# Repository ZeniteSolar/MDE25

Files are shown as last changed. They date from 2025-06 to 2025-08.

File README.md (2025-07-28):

<!-- PROJECT LOGO -->
<br />
<div align="center">
  <a href="https://github.com/ZeniteSolar/MDE25">
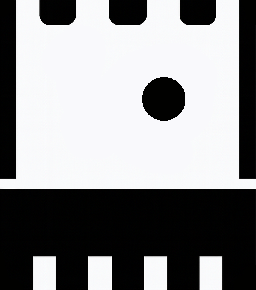
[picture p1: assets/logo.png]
Project Logo
    
  </a>

  <h3 align="center">Módulo de Direção Elétrica 2025 (MDE25)</h3>
</div>

# Visão Geral do Sistema

O sistema de direção elétrica do barco solar é composto por duas placas interligadas, uma de controle e outra de potência. O propósito do sistema é ser capaz de controlar o leme do barco conforme comandos recebidos pela rede CAN do barco enviados pelo Módulo Interface de Controle (MIC).

O barco contém atualmente a revisão [MDE22](https://github.com/ZeniteSolar/MDE22). Como pode ser visto, atualmente o barco contém uma bateria auxiliar de 12V dedicada para alimentar o sistema de direção elétrica, algo que não é tão proveitoso, sendo que o barco possui um banco de baterias principal que é mais que capacitado para alimentar o sistema de direção elétrica. Assim sendo, a bateria auxiliar implica em peso e eletrônica adicional, sendo que requer um Módulo de Carregamento de Bateria Auxiliar.

Tendo em vista a fundamentação acima, a revisão 2025 (MDE25) tem por objetivo:

* Remover a bateria auxiliar de 12V
* Utilizar o banco de baterias principal para alimentar o sistema de direção elétrica
* Melhorar aspectos gerais do sistema, velocidade de resposta, confiabilidade, etc.

Assim sendo, os requisitos abaixo foram definidos, vale notar que vários dos valores já são conhecidos de revisões anteriores, por isso não serão abordados aqui, mas podem ser encontrados no GitHub da [Zenite Solar](https://github.com/ZeniteSolar).

## Requisitos

* Tensão de entrada: 10-60V
* Tensão de saída: 10-60V
* Corrente média nominal: 20-30A
* Corrente média máxima: 42A
* Corrente de pico máxima: 80A
* Full Bridge (Reversão Completa)

## Estrutura do Projeto

Para o desenvolvimento do sistema, tendo em vista que a fabricação das placas foi realizada localmente, ou seja, não se atinge qualidade de empresas especializadas, foi decidido que o sistema seria desenvolvido em duas placas, uma de controle e outra de potência. Permitindo tolerância a erros de fabricação maiores e facilitando a fabricação e manutenção em geral.

---

### 1. Placa de Controle

A placa de controle é responsável por realizar a parte lógica do sistema, bem como gerar as tensões baixas, $V_{DDs}$ em geral e $V_{drive}$. Assim sendo, é constituída majoritariamente por um microcontrolador, um transceptor CAN, e um conjunto de conversores Step-Down / LDOs responsáveis por gerar as tensões necessárias para o sistema.

#### Componentes Principais

* **Microcontrolador:** STM32L431
* **Comunicação:** Rede CAN a 500 kbit/s baseado no transceptor MCP2561.
* **Interfaces:**
  * Conector CAN (também fornece 18 V para alimentação)
  * UART / ST-LINK para programação e depuração
  * Conector para sensor de posição do leme (potenciômetro)
  * Conectores para encoder e fim de curso (redundância)

---

### 2. Placa de Potência

A placa de potência é um sistema extremamente simples, sendo suas únicas funções controlar o motor utilizando uma Ponte H conforme sinais de PWM recebidos da placa de controle, prover sinais de medição, ou seja (Tensão de entrada, Tensão de saída e Corrente de entrada), sendo esses já tratados para serem convertidos pelo ADC do microcontrolador da placa de controle.

## Componentes Principais

* **Topologia:** Ponte H (full-bridge) com dois drivers UCC27211DDAR e quatro MOSFETs BSC093N15NS5.
* **Sensoriamento:**
  * Corrente: shunt de 1 mΩ + amplificador de instrumentação (INA283)
* Tensão: divisor resistivo com filtro passa-baixa de 40 Hz, objetivo de reduzir ruído de chaveamento/ringing.
* **Conectores:**
  * Alimentação principal via KRE (baterias chumbo-ácido 30-42 V ou lítio até 60 V)
  * Saída para motor modelo CIM (modelo FR801‑001)
* **Dissipação térmica:**
  * 5 vias de cobre (Ø 0,7 mm) por MOSFET
  * Thermal pad de 1 mm de espessura e 1 cm² por MOSFET
  * Dissipador montado entre as placas

---

# Fluxo de Sinal e Potência

1. **Entrada de Comando:**
   A placa MIC mede a posição do volante e transmite via CAN o setpoint da posição do leme através da mensagem `CAN_MSG_MIC19_MDE_ID`.

2. **Leitura e Controle:**
   O STM32L431 recebe o comando via CAN, valida o ID e seta o setpoint no controlador PID (utilizando apenas ganho proporcional devido a testes anteriores revelarem conflito entre piloto e ganho integral), que por consequência ajusta o PWM dos drivers conforme o erro entre o setpoint e a posição do leme.

3. **Ponte H:**
   Os drivers UCC27211 acionam os MOSFETs BSC093N15NS5 conforme o PWM gerado. Sendo que pode ser controlada tanto a direção quanto a velocidade do motor através da direção da corrente estabelecida pelo chaveamento e o duty cycle do PWM.

4. **Motor e Feedback:**
   O motor movimenta o leme, cuja posição é retroalimentada via um potenciômetro de 10 kΩ acoplado ao eixo e lido pelo ADC do STM32L431, que por sua vez atualiza a posição atual no controlador PID.

5. **Proteções e Limites:**
   * Monitoramento de corrente via shunt
   * Faixa de tensão de entrada: 10 V a 60 V
   * Faixa de tensão de saída: 0 V a 12 V (Motor projetado para 12 V)
   * Corrente média operacional: 20–30 A (No uso normal do barco)
   * Corrente contínua máxima: 42 A (com eixo travado até a queima) com picos de 80 A.
   * Potência média máxima: 425 W (Teste realizado até a queima da ponte H por incapacidade de dissipação e consequente dessolda dos MOSFETs)
   * Dissipador alcançou 60 C após 2 minutos de teste com reversão contínua, ou seja, ir de um extremo ao outro do leme (condição não usual)

---

# Etapas da Placa de Potência

## Entrada

Função de receber a tensão da bateria principal e alimentar a ponte H. Possui um fusível de 20 A para proteção e um banco de capacitores para estabilização da tensão que será utilizada pela ponte H.

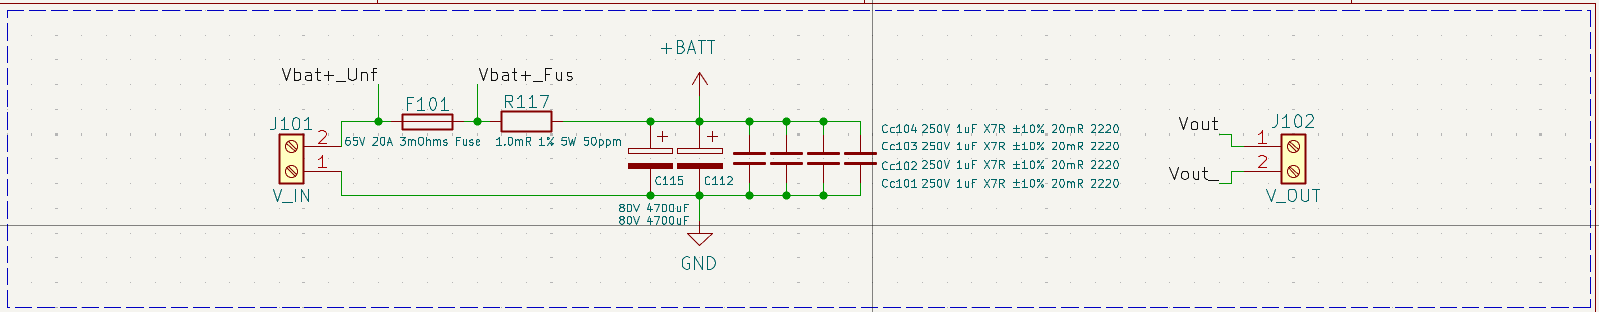
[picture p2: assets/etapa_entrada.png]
Etapa de Entrada Placa de Potência


* Conector KRE de alimentação (bateria principal)
* Fusível de 20 A
* Shunt de 1 mΩ para medição de corrente
* Filtros:
  * 2 × 470 µF eletrolíticos
  * 4 × 1 µF cerâmicos para redução de ripple e compensação de indutâncias parasitas

---

## Drivers

Os drivers são responsáveis por converter o sinal de PWM (Baixa tensão 3.3V e baixa capacidade de corrente) para um sinal de gate apropriado para os MOSFETs, além de que, por se tratar de uma ponte H completa, é necessário um driver com capacidade de chavear MOSFETs high-side e low-side. Assim sendo, foram utilizados dois drivers UCC27211DDAR, um para cada braço da ponte H. Mais especificações podem ser encontradas no datasheet do driver [UCC27211DDAR](https://www.ti.com/lit/ds/symlink/ucc27211.pdf) e no texto abaixo.

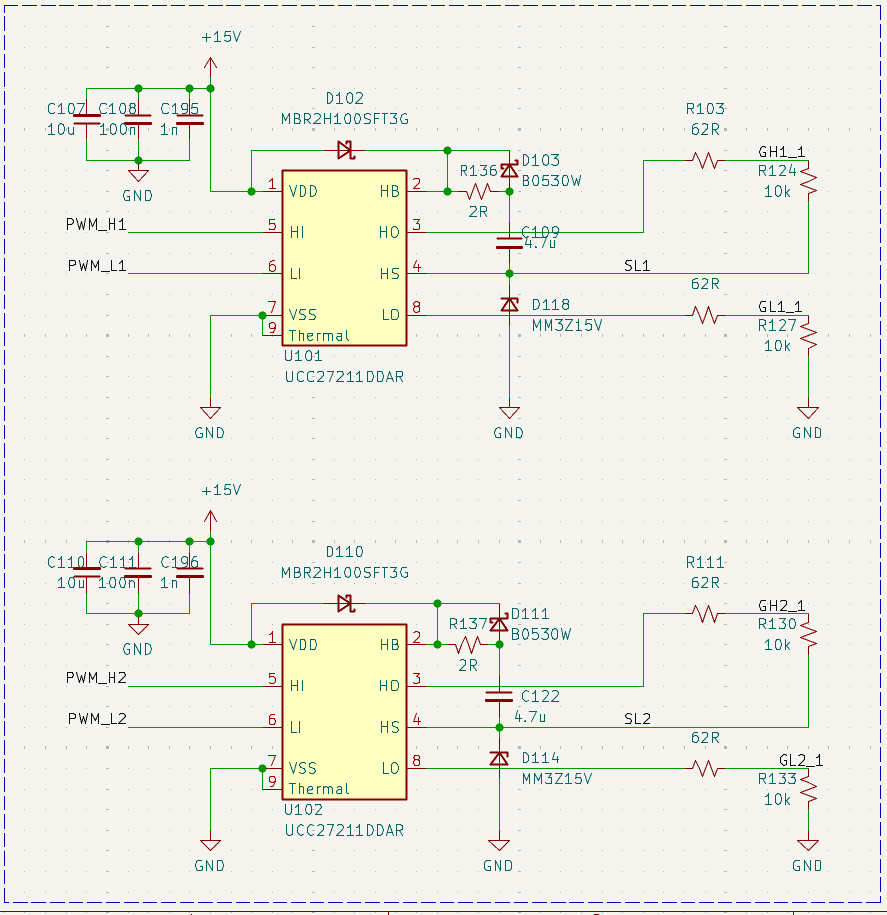
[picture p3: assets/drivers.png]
Drivers


* 2 × UCC27211DDAR (meia ponte, tecnologia bootstrap)
* Acionamento complementar com limitação de corrente de gate por resistores de 62 Ω, ajustado em laboratório conforme notas de aplicação [External Gate Resistor Design Guide for Gate Drivers](https://www.ti.com/lit/ab/slla385a/slla385a.pdf)
* Resistores de 10 kΩ entre gate e source para evitar operação na região linear quando em alta impedância.
* Proteções adicionais conforme [Bootstrap Circuitry Selection for Half-Bridge
Configurations](https://www.ti.com/lit/an/slua887a/slua887a.pdf):
  * 2 diodos para proteção
  * Resistor de 2 Ω para limitar corrente de bootstrap

---

## Ponte H (MOSFETs + Snubber)

A ponte H é composta por quatro MOSFETs, dois para cada braço da ponte H, sendo que cada braço é composto por um MOSFET high-side e um MOSFET low-side, permitindo a reversão completa do motor e controle de velocidade através do duty cycle do PWM.

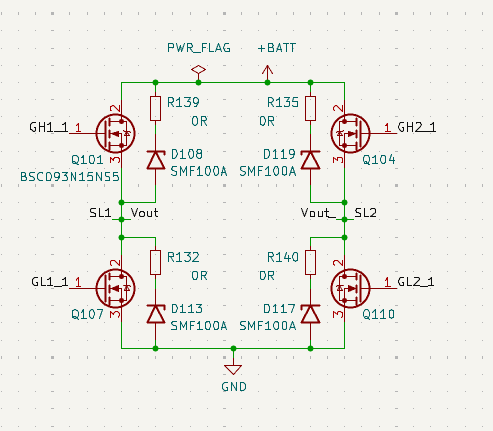
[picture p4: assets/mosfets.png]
Ponte H


* 4 × BSC093N15NS5 (150 V, 87 A, R<sub>DS(on)</sub> = 9,3 mΩ)
* Proteção por snubber com TVS de 111 V (breakdown), 160 V (clamping)
* Estratégia de chaveamento:

  * Um braço da ponte permanece fixo (conduzindo), o outro chaveia.
  * O braço fixo alterna de acordo com o sentido do motor.
  * Para evitar sobrecarga no bootstrap, é garantido no controlador que o MOSFET acionado no braço fixo seja sempre o MOSFET low-side, assim sendo, o bootstrap não será completamente descarregado, pois o MOSFET high-side não conduzirá, evitando entrada na região linear dos MOSFETs.

---

## Sensor de Corrente (Entrada)

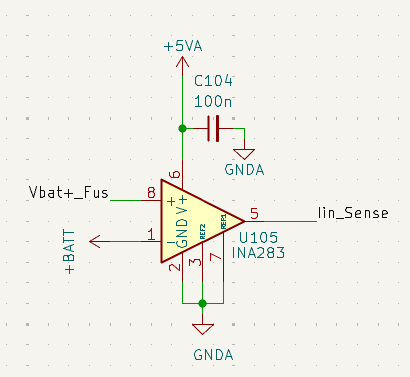
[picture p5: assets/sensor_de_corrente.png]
Sensor de Corrente


* Shunt de 1 mΩ + amplificador INA283 (ganho de 50 V/V)
* Saturação a 3,3 V → Corrente máxima medida ≈ 66 A

---

## Sensor de Tensão (Entrada e Saída)

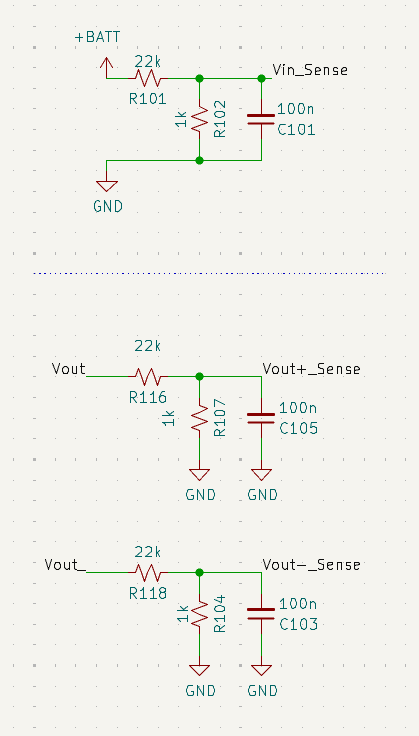
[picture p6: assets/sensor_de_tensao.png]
Sensor de Tensão


* Divisor resistivo para adequar até 60 V para 2,6 V
* Filtro passa-baixa de 100 nF a 40 Hz
* Margem contra saturação do ADC e interferência do zener de proteção (3,3 V)
> Para medição da tensão de saída deve ser utilizado modo diferencial do ADC, assim sendo possível a medição da tensão tanto positiva quanto negativa. Isso ocorre pois, dependendo do sentido da corrente, a tensão de saída pode ser positiva ou negativa.

---

# Placa de Controle

A placa de controle, como já mencionado, é responsável por realizar as seguintes funções:

* Gerar níveis de tensão baixos (15V, 5V, 3.3V), note-se que o conector RJ45 da rede CAN já fornece 18V.
* Receber o setpoint desejado pelo piloto através da rede CAN.
* Monitorar a posição do leme através do potenciômetro.
* Gerar uma ação de controle para o motor através do PWM.

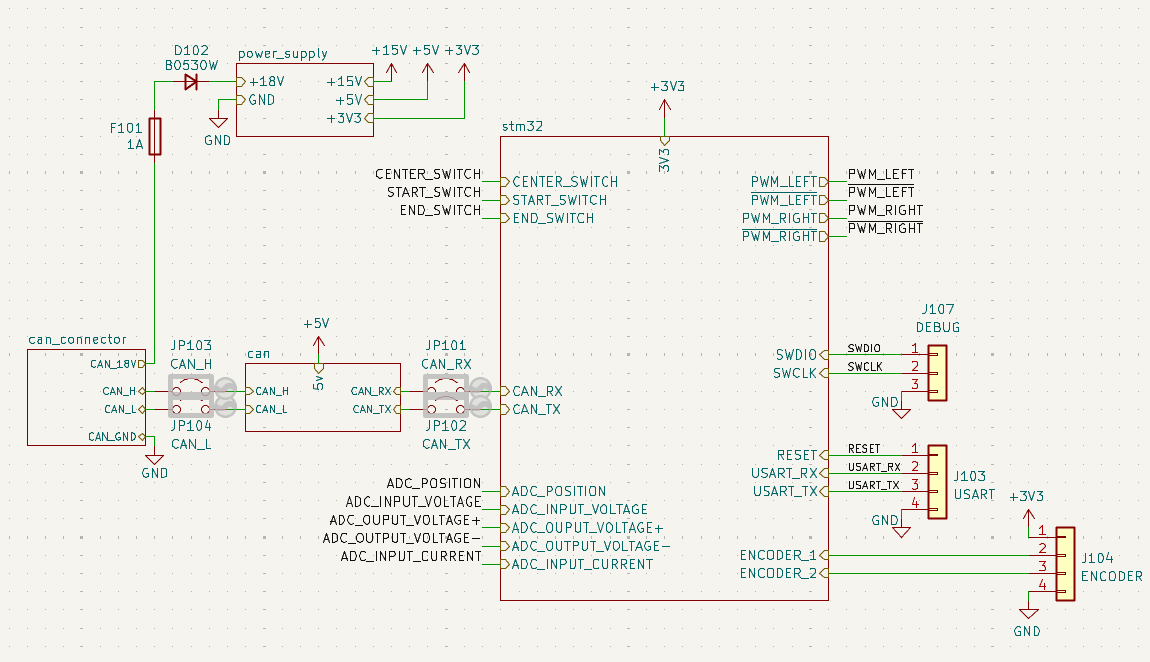
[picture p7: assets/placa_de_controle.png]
Placa de Controle


* Alimentação lógica e dos drivers por 18 V da rede CAN
* Comunicação CAN conforme padrão do barco solar
* MCU STM32L431:
  * Leitura de posição do leme (potenciômetro via ADC)
  * Implementação do controle proporcional
  * Geração do PWM de controle para os drivers

# Implementação do Projeto

Dado que praticamente todos os componentes já eram impostos (Já existiam no inventário da Zenite Solar e não podiam ser adquiridos novos atualmente), o projeto foi simplesmente a realização dos requisitos. Assim sendo, foi utilizado o software KiCad para a elaboração do projeto.

[Esquemático da Placa de Controle](./hardware/control/outputs/control.pdf)

[Esquemático da Placa de Potência](./hardware/power/outputs/power.pdf)

Com o projeto em mãos, foi realizada a fabricação das placas, ambas placas foram fabricadas localmente utilizando-se a técnica de fotolitografia com tinta UV e uma impressora de resina Elegoo Mars 2 PRO para a exposição UV. Os químicos utilizados foram os padrões para esse tipo de processo (Carbonato de Sódio 1%, Percloreto de Ferro e Acetona). Após a manufatura, ambas placas foram estanhadas, tendo em vista que o ambiente de trabalho é propenso à corrosão e o estanhamento melhora a vida útil das placas.

## Placa de Controle
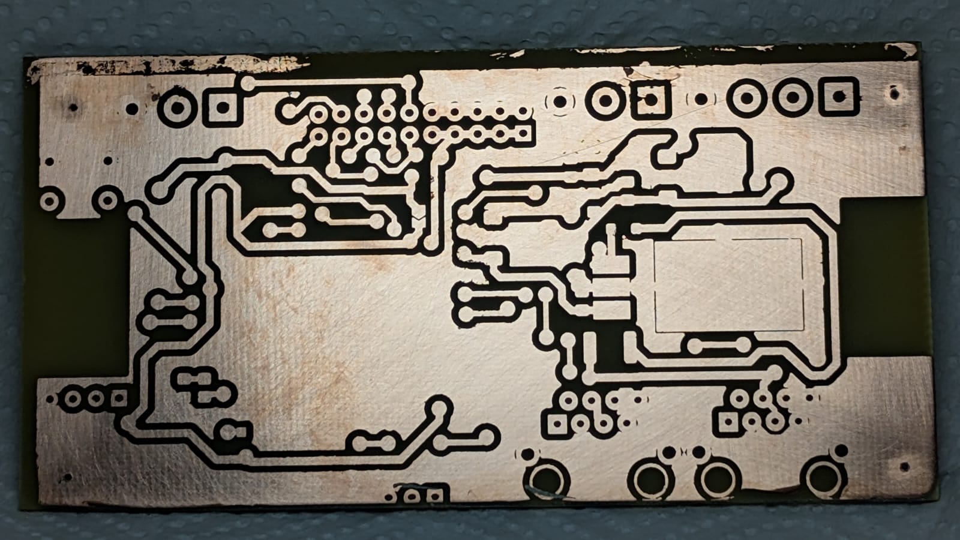
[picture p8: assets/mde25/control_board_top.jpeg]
Placa de Controle Topo

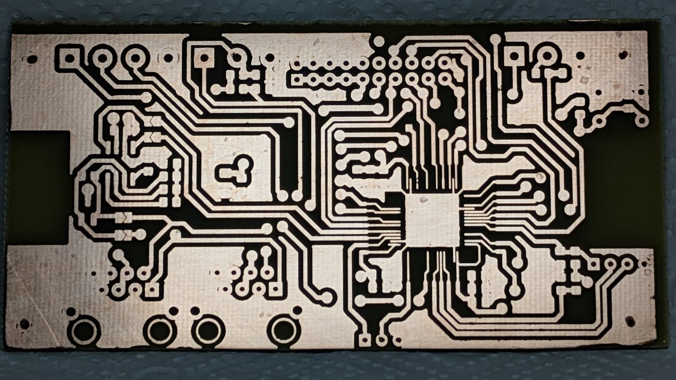
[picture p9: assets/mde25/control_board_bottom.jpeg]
Placa de Controle Base


## Placa de Potência
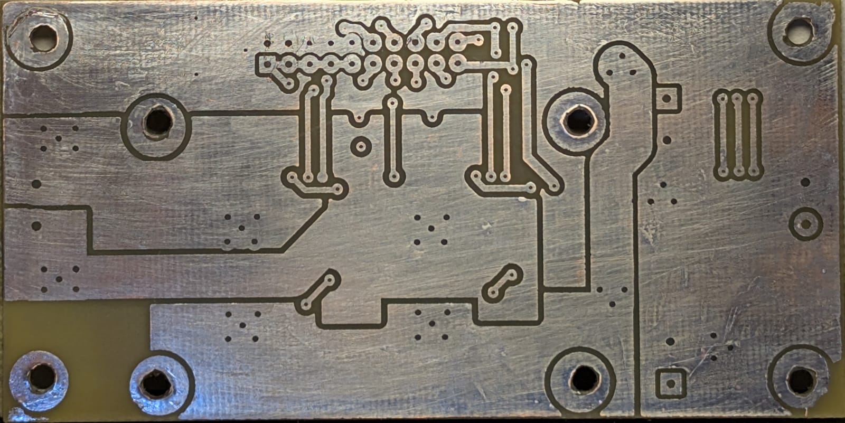
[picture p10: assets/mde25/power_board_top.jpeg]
Placa de Potência Topo

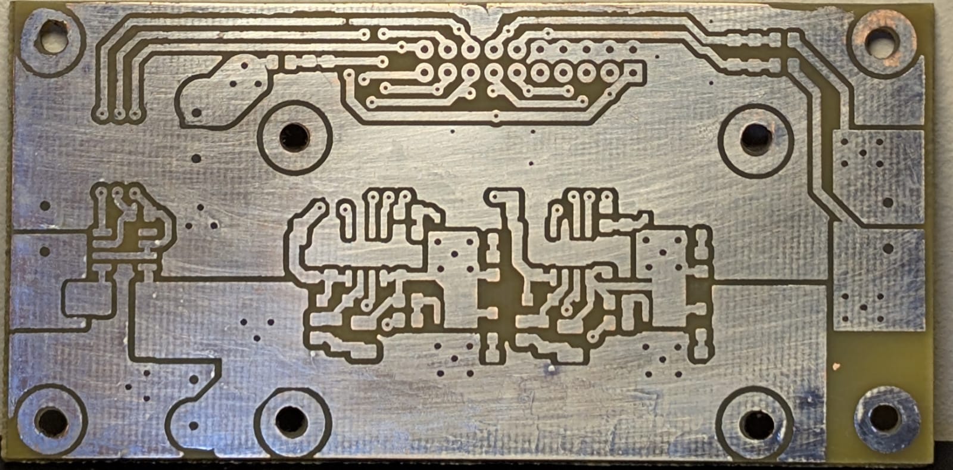
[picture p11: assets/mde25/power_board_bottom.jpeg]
Placa de Potência Base


## Placa de controle montada

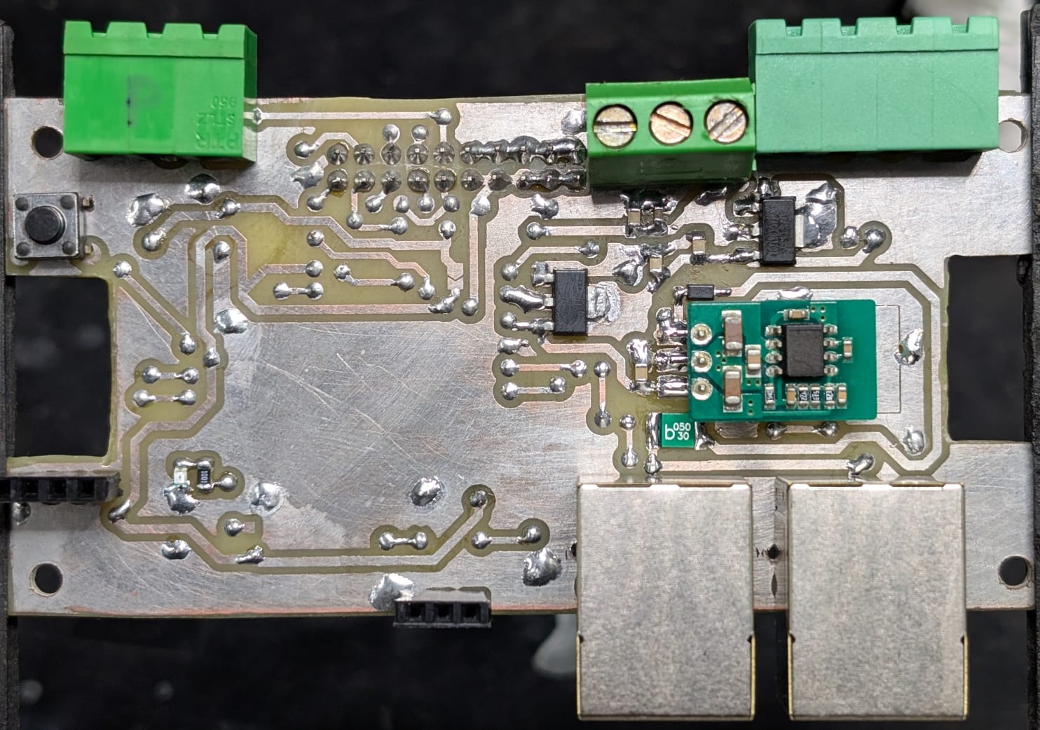
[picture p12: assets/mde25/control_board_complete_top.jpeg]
Placa de Controle Montada Topo

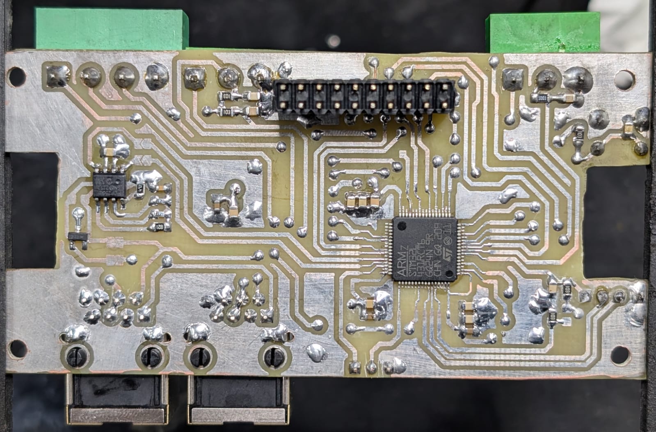
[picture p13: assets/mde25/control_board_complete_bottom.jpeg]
Placa de Controle Montada Base


## Placa de potência montada

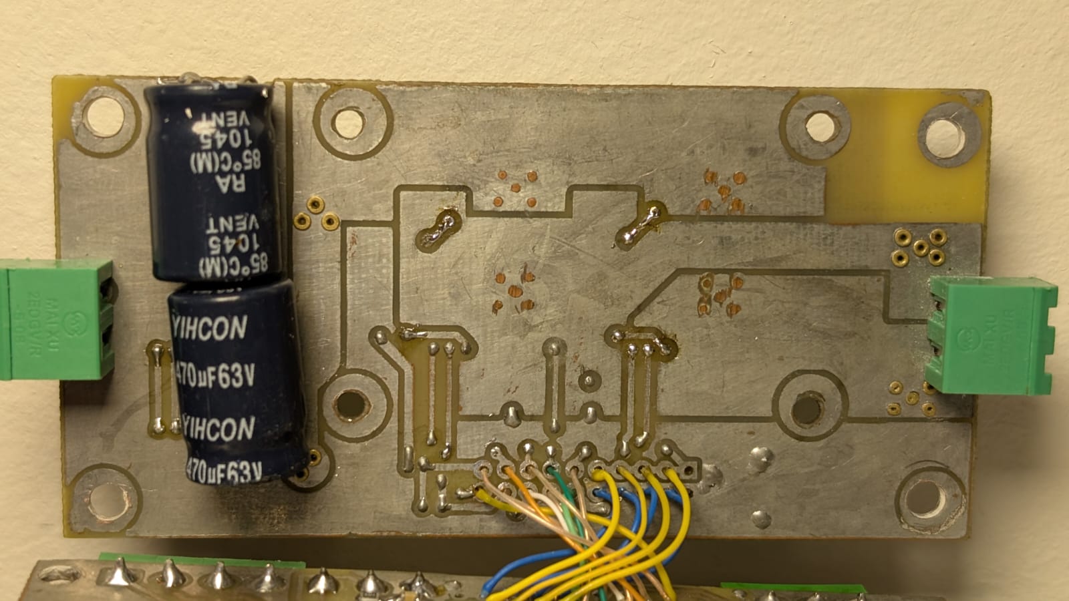
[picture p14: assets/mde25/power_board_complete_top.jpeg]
Placa de Potência Montada Topo

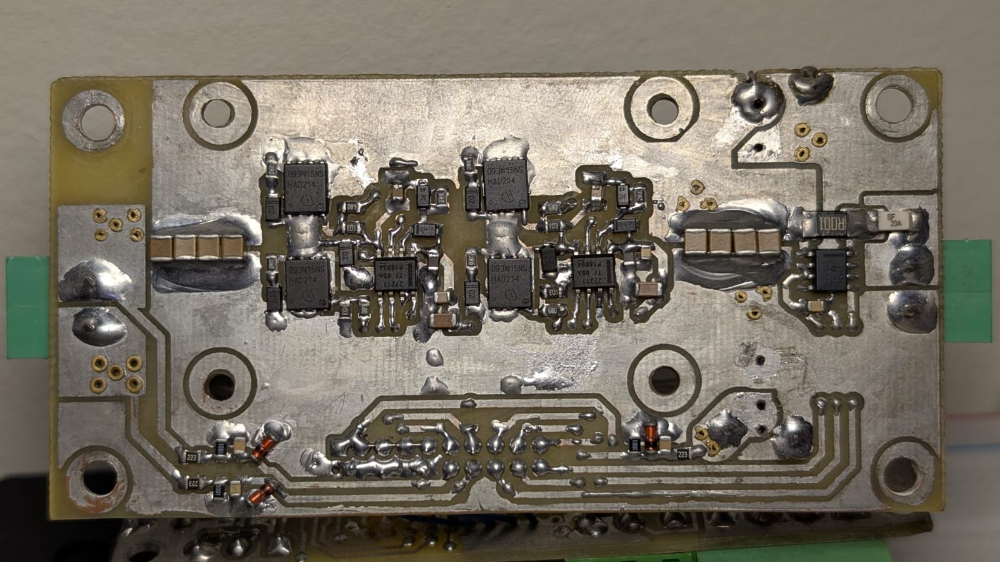
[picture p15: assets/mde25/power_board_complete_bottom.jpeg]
Placa de Potência Montada Base


## Sistema de dissipação térmica

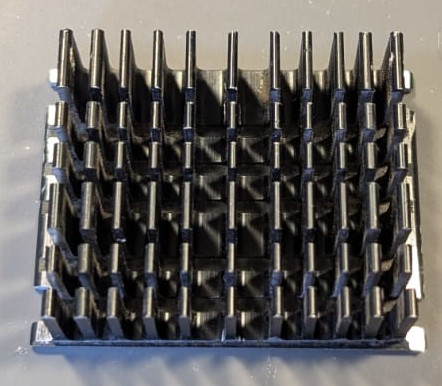
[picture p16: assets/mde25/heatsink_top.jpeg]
Dissipador 1


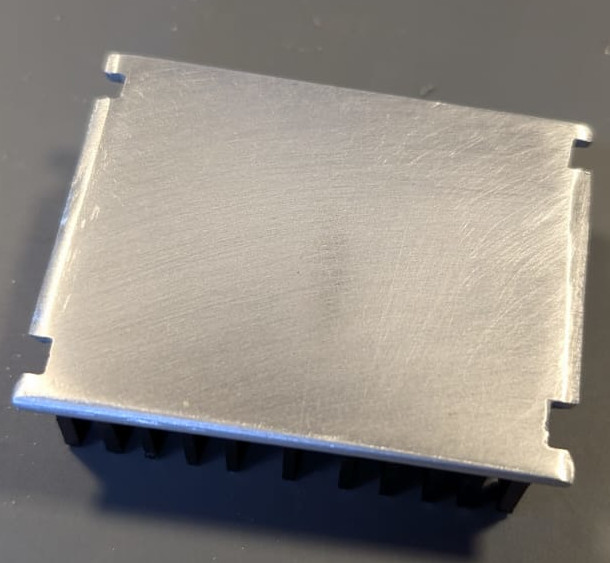
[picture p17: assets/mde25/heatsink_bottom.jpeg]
Dissipador 2


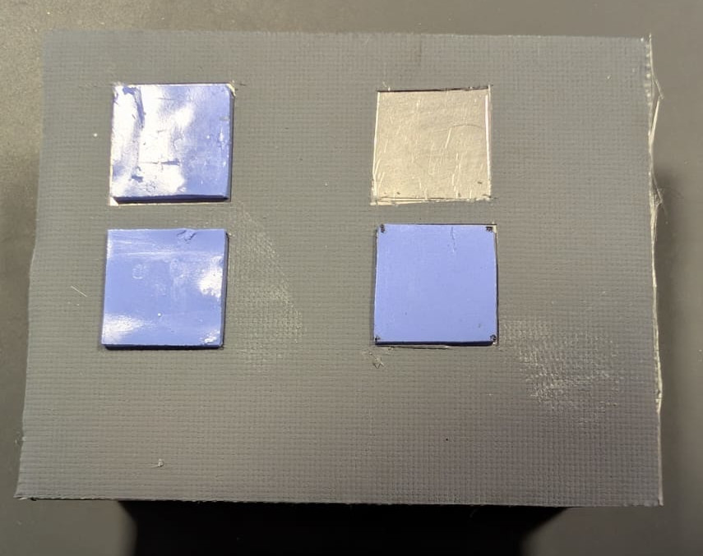
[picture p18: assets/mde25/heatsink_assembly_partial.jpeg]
Dissipador 3


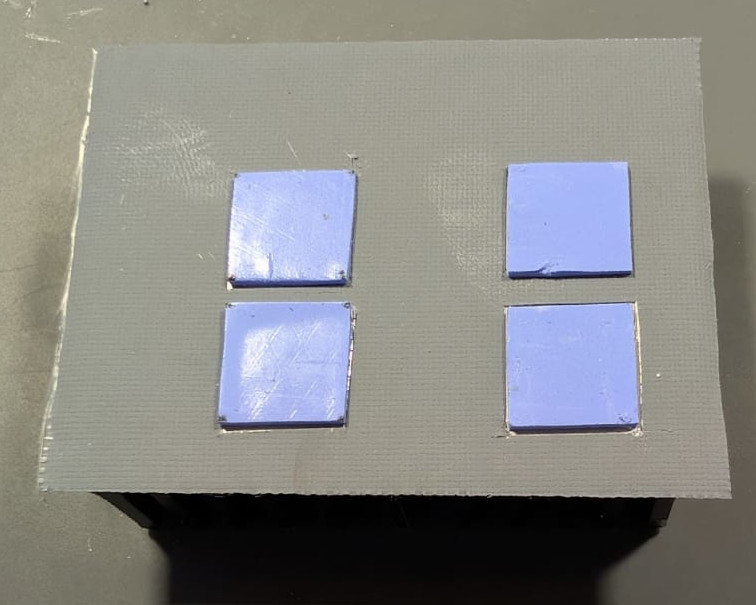
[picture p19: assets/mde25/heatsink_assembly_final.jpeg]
Dissipador 4


## MDE25 - Montagem Final

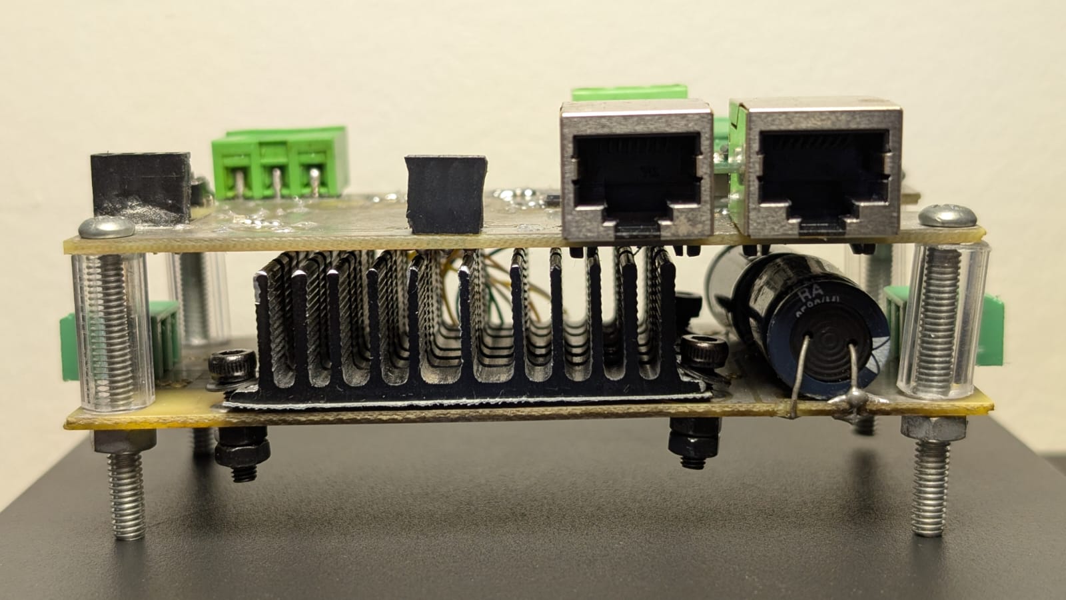
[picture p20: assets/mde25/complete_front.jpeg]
MDE25 - Montagem Final Frente


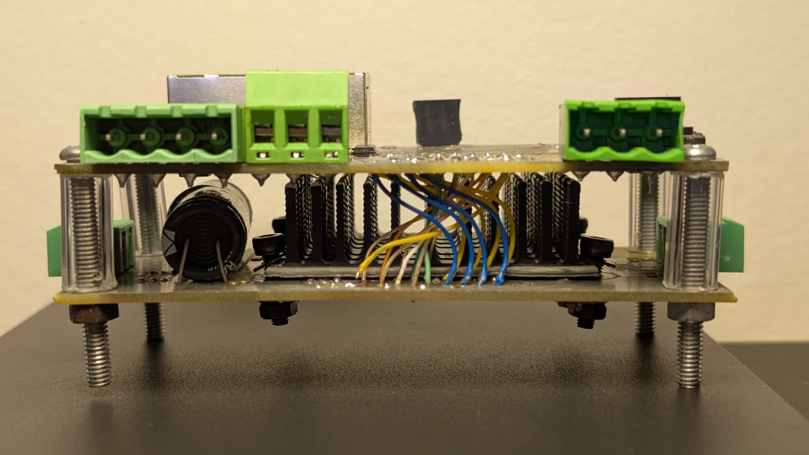
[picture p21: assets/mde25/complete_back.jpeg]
MDE25 - Montagem Final Trás


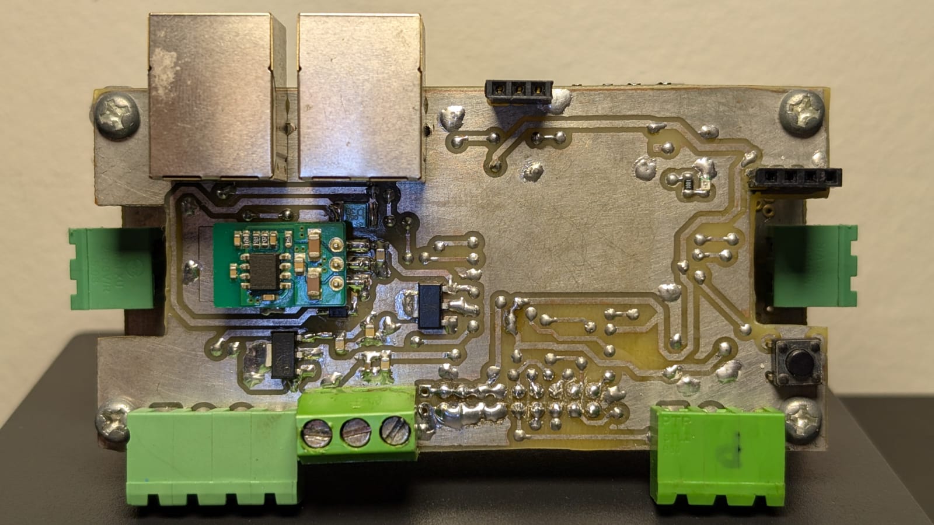
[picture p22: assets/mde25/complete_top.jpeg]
MDE25 - Montagem Final Topo


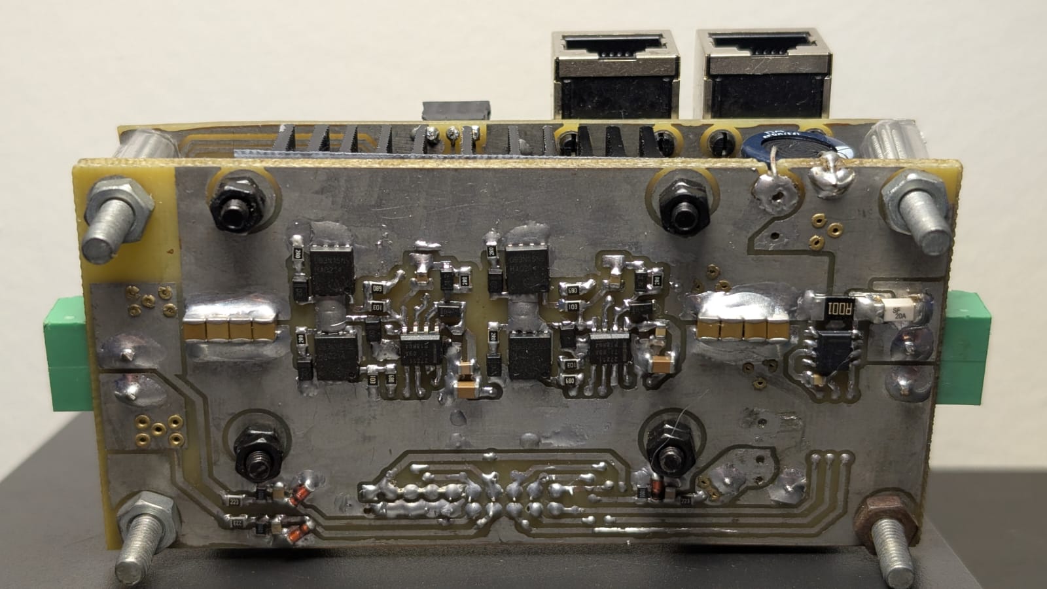
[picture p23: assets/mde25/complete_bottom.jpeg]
MDE25 - Montagem Final Base


---

# Testes

Para monitoramento/ajustes, um pequeno aplicativo Python foi desenvolvido, pode-se encontrar [Aqui](./firmware/Extra/TelemetryPanel/panel.py). Esse aplicativo foi utilizado para verificar comportamento do sistema e ajustar o controlador PID.

## Simples exemplo de um teste em hardware real (Direção + Leme) aproximando uma resposta ao degrau

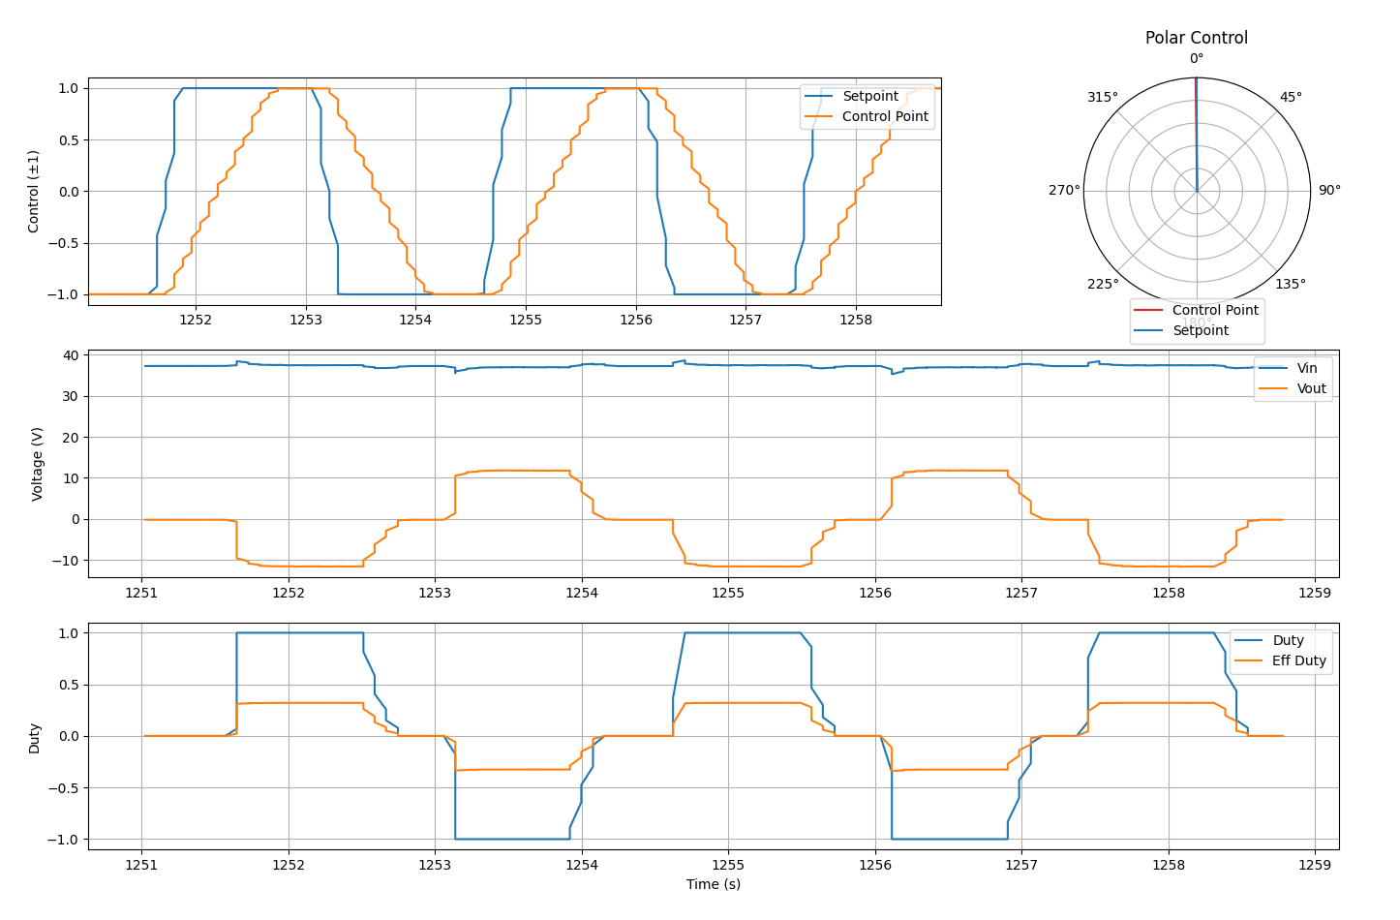
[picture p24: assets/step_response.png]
Resposta ao degrau


## Simples exemplo de um teste em hardware real (Direção + Leme) aproximando um setpoint seguindo uma onda triangular

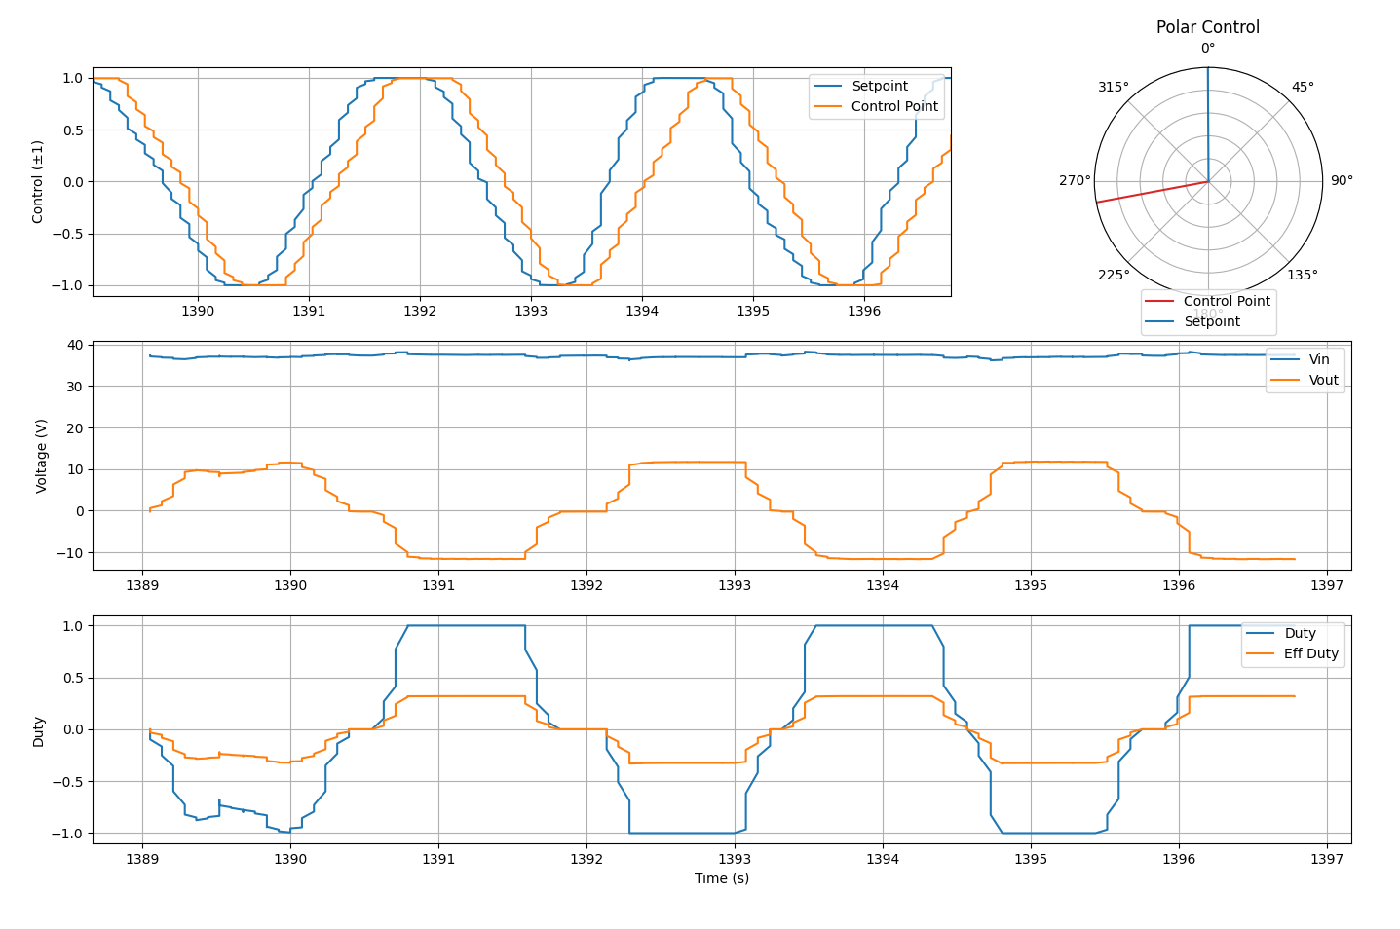
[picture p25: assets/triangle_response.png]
Setpoint triangular


Como pode ser visto, o sistema operou corretamente conforme o esperado, abaixo mais detalhes sobre os testes são apresentados.

## Limite a limite velocidade constante

Foi realizado um teste com o volante indo de limite a limite a velocidade constante:

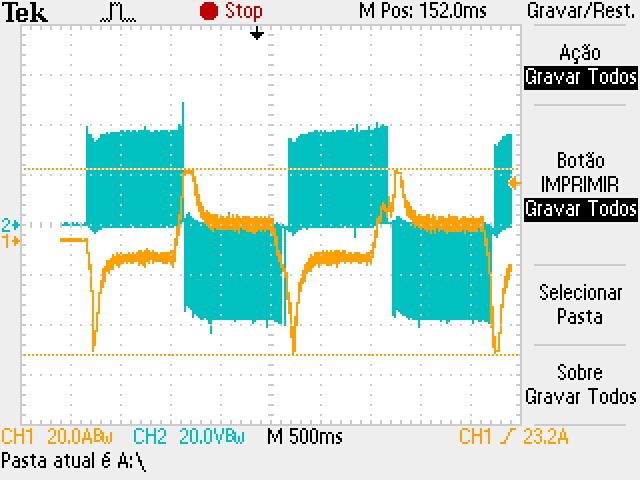
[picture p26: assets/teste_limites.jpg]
Teste de Limite a Limite Velocidade Constante


* O motor leva cerca de 1s para atingir o extremo oposto (Ótimo tempo de resposta)
* Na reversão, consome cerca de 40 A por 500 ms
* Corrente estabiliza em torno de 11 A após aceleração
* Temperatura do dissipador atingiu 60 C após 2 min de teste contínuo (Esse comportamento de teste contínuo não é um caso esperado que o piloto realize em operação normal)

## Teste de queima

Após a validação do sistema, desejou-se testar a capacidade de sobrecarga do MDE25, para assim entender os limites e como o sistema vem a falhar. Para isso, o eixo do leme foi travado e o piloto comandou a direção de um extremo ao outro do leme.

As métricas do painel de monitoramento foram as seguintes:

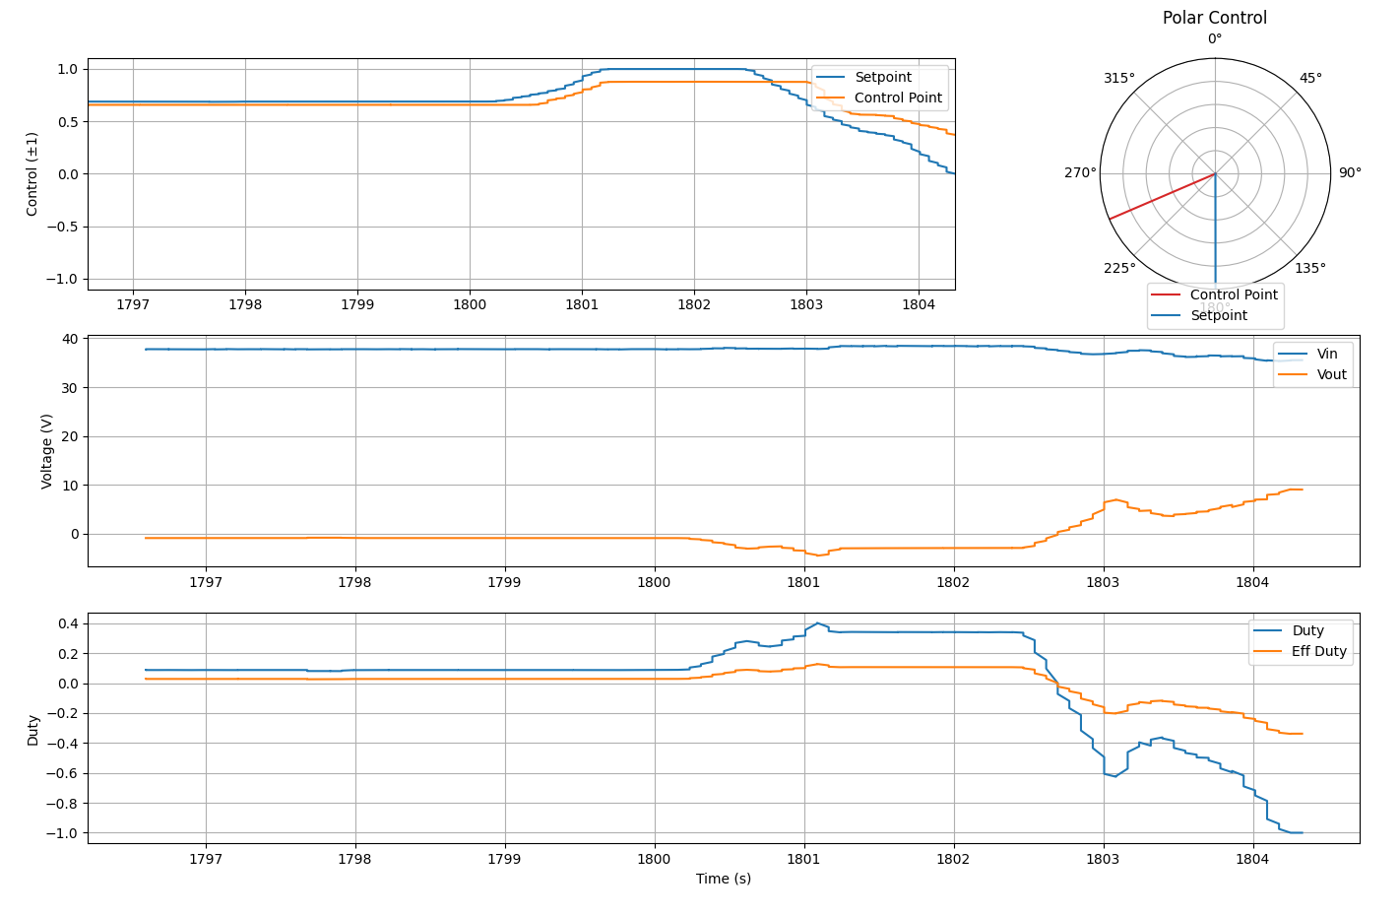
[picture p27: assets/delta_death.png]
Teste de queima


Foi necessário cerca de 30 segundos para que o sistema entrasse em sobrecarga e viesse a queima. Como pode ser visto pelo painel, no momento em que entra em sobrecarga, a tensão na bateria principal caiu cerca de 4V. Indo de aproximadamente 38V para 34V, isso demonstra que um estresse muito grande foi aplicado ao sistema, tendo em vista que se trata de um banco de baterias de chumbo com alta capacidade de corrente. Após a queima, o sistema foi desmontado e averigou-se a causa da queima.

## Detalhes da queima e notas sobre o sistema

Dado que os MOSFETs utilizados realizam a sua troca de calor com o dissipador por um pad térmico, ou seja, a transferência não é realizada pelo case do componente, mas sim pelo seu pad de dreno, é necessário que a placa seja capaz de conduzir esse calor de forma efetiva para o dissipador, assim foram feitas vias de cobre (5 vias de 0.7mm para cada MOSFET). Segue abaixo a foto das vias térmicas.

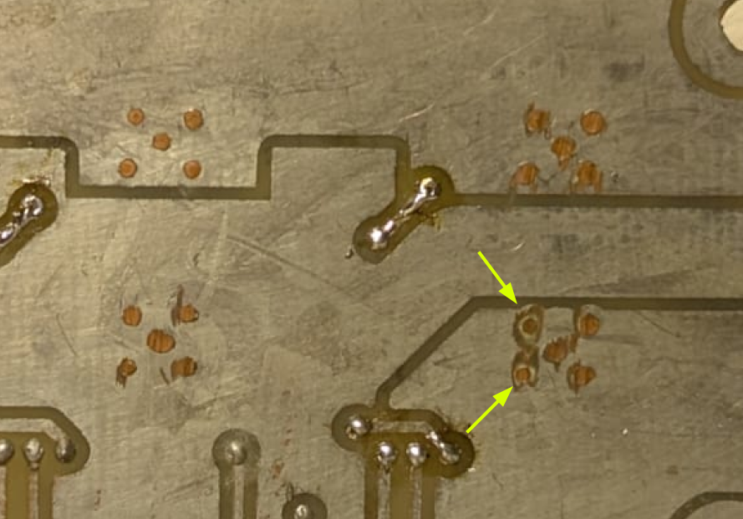
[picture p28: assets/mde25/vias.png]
Vias Térmicas


Como pode ser observado, um dos conjuntos de vias ficou apenas com 3 vias efetivamente transferindo calor, pois 2 acabaram sendo lixadas pelo processo de fabricação, isso resultou com que o MOSFET associado com essas vias viesse a sobreaquecer e dessoldar, não sendo o calor diretamente a causa da queima, mas sim a dessolda do MOSFET que resultou em uma gota de solda dando curto no braço da ponte H e após isso gerando a queima. Segue foto do MOSFET queimado.

<div style="text-align: center; max-width: 20%; margin: 0 auto;">
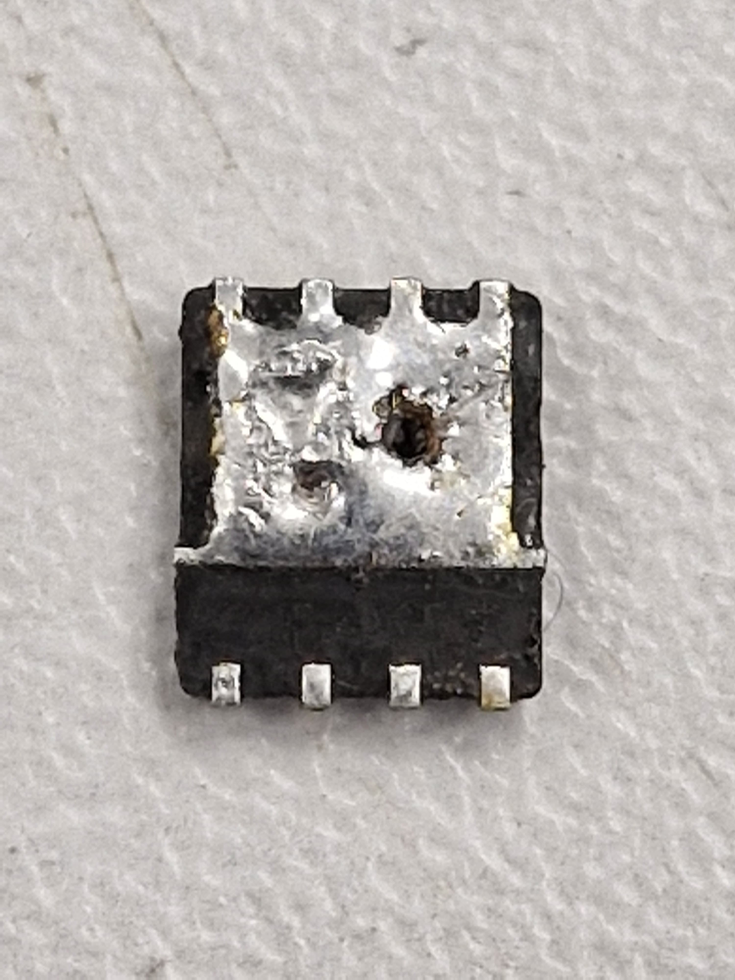
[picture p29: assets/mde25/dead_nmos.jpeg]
MOSFET Queimado
  
</div>

# Notas extras sobre estimativa da Indutância do Motor

Para estimar a indutância do motor, utilizamos o ripple de corrente observado em regime permanente com o motor em velocidade constante.

## Parâmetros do teste:

* Corrente média: **11 A**
* Ripple de corrente: **10%** → $\Delta I = 1{,}1\,\text{A}_{pp}$
* Tensão de alimentação: **36 V**
* Duty cycle: **40%**
* Frequência de PWM: **20 kHz** (→ período $T_s = 50\,\mu\text{s}$)
* Topologia: **Ponte H full-bridge com modulação bipolar**

## Modelo de cálculo:

Assumindo modulação bipolar, a variação de corrente durante o ciclo de comutação é dada por:

$$
\Delta I = \frac{2 \cdot V \cdot D \cdot T_s}{L}
\Rightarrow
L = \frac{2 \cdot V \cdot D \cdot T_s}{\Delta I}
$$

Substituindo os valores:

$$
L = \frac{2 \cdot 36\,\text{V} \cdot 0{,}4 \cdot 50 \times 10^{-6}\,\text{s}}{1{,}1\,\text{A}}
= \frac{1{,}44 \cdot 10^{-3}}{1{,}1}
\approx 1{,}31\,\text{mH}
$$

## Resultado:

A indutância estimada do motor é:

$$
\boxed{L \approx 1{,}31\;\text{mH}}
$$

# Sobre o Firmware

## Arquitetura de Software

O firmware está organizado em módulos funcionais especializados:
- **Core/control**: Implementação do controlador PID
- **Core/pwm**: Geração de sinais PWM para ponte H
- **Core/sense**: Aquisição de dados via ADC
- **Core/CAN**: Servidor de comunicação CAN
- **Core/uart_server**: Interface de debug e configuração
- **Core/telemetry**: Sistema de monitoramento
- **Core/status**: Gerenciamento de estado e feedback sonoro

## Configuração do Sistema

O firmware possui diversos parâmetros que podem ser ajustados para otimizar o sistema para as necessidades do usuário, esses podem ser ajustados no arquivo de configuração [config.h](./firmware/Core/Inc/config.h).

## Módulos de Firmware

### 1. Módulo de Controle (Core/control)

#### Funcionalidades Principais
O módulo implementa um controlador PID digital completo (control.c) com as seguintes características técnicas:

**Parâmetros de Controle:**
- Ganho Proporcional (Kp): 2.8 (inicial, configurável)
- Ganho Integral (Ki): 0.0 (inicial, configurável)
- Ganho Derivativo (Kd): 0.0 (inicial, configurável)
- Janela de média móvel: 15 amostras para filtragem de setpoint para evitar mudança abrupta de setpoint.

**Algoritmo PID:**
```
error = setpoint - feedback
integral += error * dt
integral = clamp(integral, -0.1, 0.1)  // Anti-windup
derivative = (error - error_previous) / dt
output = Kp * error + Ki * integral + Kd * derivative
```

**Características de Implementação:**
- **Filtragem de Setpoint** (control.c): Média móvel de 15 amostras para suavizar comandos de entrada e reduzir oscilações
- **Saturação de Saída**: Limitação entre -1.0 e +1.0 com zona morta configurável
- **Anti-windup**: Limitação da integral entre -0.1 e 0.1 para evitar saturação
- **Período Dinâmico**: Baseado na frequência real de amostragem do ADC
- **Lock de Setpoint**: Capacidade de travamento para operação manual

### 2. Módulo PWM (Core/pwm)

#### Geração de Sinais PWM
O módulo controla a ponte H através de dois canais PWM complementares (pwm.c):

**Especificações Técnicas:**
- **Timer**: TIM1 (Advanced Timer) utilizado para gerar os sinais PWM.
- **Frequência Base**: 24 kHz (configurável acima de 1.3 kHz)
- **Resolução**: 16 bits
- **Canais**: CH1 e CH2 com saídas complementares (CHxN)

**Compensação de Tensão** (pwm.c):
O sistema implementa compensação automática baseada na tensão de entrada:
```
max_duty = PWM_MAX_OUT_VOLTAGE / clamped_input_voltage;
effective_duty = map(input_duty, -1.0, 1.0, -max_duty, max_duty);
```

**Características de Segurança:**
- **Zona Morta**: Configurável (-0.06 a +0.06) para evitar vibrações e perda de energia sem realização de movimento útil.

#### Configurações
- **Tensão Máxima de Saída (Ajustável)**: 12V
- **Faixa de Tensão de Entrada**: 24V a 60V
- **Dead Time**: Configurado para proteção da ponte H, otimizado em laboratório para melhor tempo sem gerar curto no braço.

### 3. Módulo de Sensoriamento (Core/sense)

#### Aquisição de Dados ADC
Sistema de conversão analógico-digital de 4 canais simultâneos (sense.c:10-16):

**Canais de Conversão:**
```
typedef enum {
  ADC_RANK_CURRENT_CONTROL_POINT = 0U,  // Posição do leme
  ADC_RANK_INPUT_VOLTAGE = 1U,           // Tensão de entrada
  ADC_RANK_OUTPUT_VOLTAGE = 2U,          // Tensão de saída
  ADC_RANK_INPUT_CURRENT = 3U,           // Corrente de entrada
} adc_ranks_t;
```

**Características Técnicas:**
- **Resolução**: 16 bits (65535 níveis) (Com Oversample, dado cru 12 bits)
- **Modo**: Conversão contínua via DMA
- **Trigger**: Timer 2 (frequência configurável) atrelado também a atualização da malha de controle.
- **Buffer**: Circular DMA para aquisição contínua

**Calibração e Linearização:**
Cada canal possui calibração específica (sense.c), calibrações do ADC podem ser feitas utilizando o seguinte [script](./firmware/Extra/ADC_Linearization/linearization.py):
- **Tensão de Entrada**: `V = 0.001150 * ADC - 0.088064`
- **Tensão de Saída**: `V = 0.002327 * ADC - 73.731254`
- **Posição**: `P = (ADC * 2.0 / 65535.0) - 1.0` (normalizada ±1.0)
- **Corrente**: `I = ADC * 3.3 / 65535.0` (referência 3.3V)

### 4. Servidor CAN (Core/CAN)

#### Protocolo de Comunicação
Implementa cliente CAN para recepção de comandos do MIC19 (can_server.c):

**Filtro CAN** (can_server.c):
- **Modo**: ID Mask para filtragem seletiva
- **Banco**: 0 (FIFO0)
- **Máscara**: 0x7FF (11 bits de ID padrão)

**Especificações do Protocolo:**
- **ID da Mensagem**: 31 (CAN_MSG_MIC19_MDE_ID)
- **Comprimento**: 4 bytes
- **Frequência**: 50 Hz
- **Assinatura**: 240 (CAN_SIGNATURE_MIC19)

**Estrutura da Mensagem:**
```
Byte 0: Assinatura (240)
Byte 1: Position_L (8 bits baixos)
Byte 2: Position_H (8 bits altos)
Byte 3: Reservado
```

**Processamento de Dados** (can_server.c):

Normalização do setpoint -1.0 a 1.0:

```
uint16_t position = rxData[1] | (rxData[2] << 8);
float steering_angle = (position / 1024.0f) * 2.0f - 1.0f;
```

#### Sistema de Watchdog
**Timeout de Comunicação** (can_server.c):
- **Timer**: TIM7 para detecção de perda de comunicação
- **Reset Automático**: Contador zerado a cada mensagem válida
- **Ação de Timeout**: Setpoint zerado e status de desconexão. Gera sinal sonoro de sequência específica de BEEP no motor. Reconexão também irá resultar em sinal sonoro de sequência específica de BEEP no motor.

### 5. Servidor UART (Core/uart_server)

#### Interface de Debug e Configuração
Sistema de comunicação serial para debug e ajuste de parâmetros (uart_server.c):

**Protocolo de Comando:**
- **Formato**: `<comando:valor>`
- **Delimitadores**: `<` (início) e `>` (fim)
- **Parser**: Máquina de estados para robustez
- **Buffer**: 128 bytes com buffer circular

**Comandos Disponíveis:**
```
'D': Set PWM duty cycle (-1.0 a 1.0)
'F': Set PWM frequency (Hz)
'p': Set PID proportional gain
'i': Set PID integral gain
'd': Set PID derivative gain
's': Set ADC sampling frequency
'L': Lock/unlock PWM (1/0)
'R': System reset
```

#### Implementação do Parser
**Máquina de Estados** (uart_server.c):
```
UART_SERVER_STATE_WAIT_START      -> Aguarda '<'
UART_SERVER_STATE_WAIT_TERMINATOR -> Coleta dados até '>'
UART_SERVER_STATE_NEW_MESSAGE     -> Mensagem completa
UART_SERVER_STATE_ERROR           -> Overflow ou erro
```
### 6. Sistema de Telemetria (Core/telemetry)

#### Estrutura de Dados
Coleta e transmite métricas do sistema (telemetry.h):

```
typedef struct {
  uint16_t preamble;           // 0x5A54
  float sense_input_voltage;   // Tensão de entrada
  float sense_input_current;   // Corrente de entrada
  float sense_output_voltage;  // Tensão de saída
  float sense_control_point;   // Posição atual
  float control_setpoint;      // Setpoint desejado
  float control_error;         // Erro de controle
  float pwm_duty;             // Duty cycle nominal
  float pwm_effective_duty;   // Duty cycle efetivo
  uint8_t status_connected;   // Status de conexão
} telemetry_t;
```

**Características de Transmissão:**
- **Frequência**: 40 Hz (intervalo de 25ms)
- **Interface**: UART a 115200 bps
- **Formato**: Printf formatado para debug
- **Habilitação**: Condicional via DEBUG_TELEMETRY_ENABLE

#### Saída de Debug
Formato de telemetria (telemetry.c):
```
"VI:%f, II:%f, VO:%f, CP:%f, SP:%f, ER:%f, D:%f, ED:%f, ST:%hu\n"
```

### 7. Módulo de Status (Core/status)

#### Sistema de Feedback Sonoro
Gerencia indicação sonora de estado do sistema (status.c):

**Sequências de Status:**
- **Conexão**: 3 tons crescentes (Baixo → Médio → Alto)
- **Desconexão**: 3 tons decrescentes (Alto → Médio → Baixo)
- **Desconectado**: Tom único alto

**Parâmetros Sonoros:**
```
#define STATUS_TONE_FREQUENCY_LOW_HZ    2093.0f  // C7
#define STATUS_TONE_FREQUENCY_MEDIUM_HZ 2794.0f  // F7
#define STATUS_TONE_FREQUENCY_HIGH_HZ   4186.0f  // C8
#define STATUS_TONE_DURATION_S          0.16f
#define STATUS_TONE_PWM_VOLUME          0.70f
```

#### Implementação Técnica
**Geração de Tom** (status.c):
- **Timer**: TIM6 para base de tempo
- **Modulação**: PWM alternado entre +70% e -70%
- **Cálculo de Frequência**: `repetitions = duration / (1/frequency)`
- **Callback**: Sistema de callbacks encadeados para sequências

**Controle de Estado:**
- **Variável Global**: `device_connected` para rastreamento
- **Transições**: Apenas em mudanças de estado
- **Proteção**: Evita múltiplas execuções da mesma sequência

### 8. Utilitários Matemáticos (utils.h)

```
float clampf(float value, float min, float max);
// Limita valor entre mínimo e máximo

float passf(float value, float replace, float cut_min, float cut_max);
// Zona morta - substitui valores dentro de faixa

float mapf(float value, float min_in, float max_in, float min_out, float max_out);
// Mapeia valor de uma faixa para outra
```

### Configuração de Periféricos
**Timers Utilizados:**
- **TIM1**: PWM principal (24 kHz, centro-alinhado)
- **TIM2**: Trigger para ADC (frequência configurável)
- **TIM6**: Base de tempo para status sonoro
- **TIM7**: Watchdog de comunicação CAN

**DMA Channels:**
- **ADC1**: Conversão contínua 4 canais
- **UART1**: Recepção com idle detection

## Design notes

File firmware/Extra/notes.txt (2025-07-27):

max input current: 8A

max dead current input, running with blocked axis: 12.17 (35V) = 426W morreu por dessolda

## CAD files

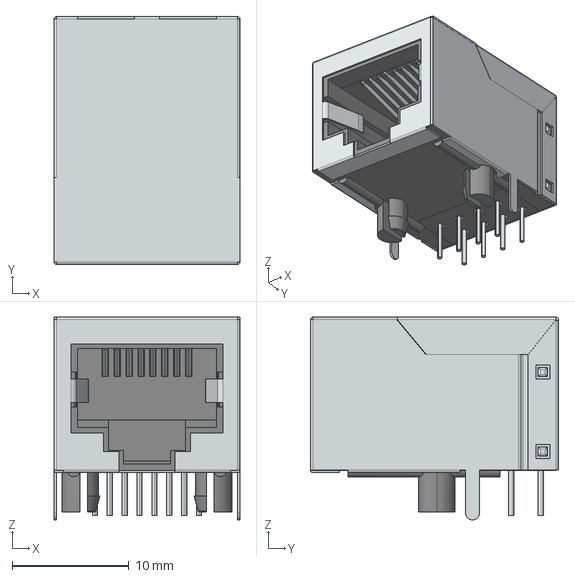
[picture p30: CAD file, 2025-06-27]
hardware/control/ZeniteKicadLib/rj45.step
15.9 x 21.2 x 17.3 mm

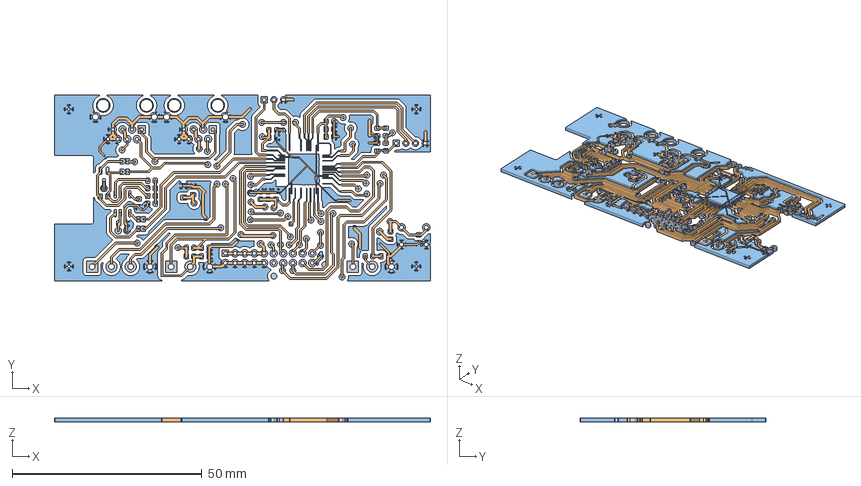
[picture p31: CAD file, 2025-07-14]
hardware/fabrication/control_bu.FCStd
99.1 x 49.0 x 1.01 mm

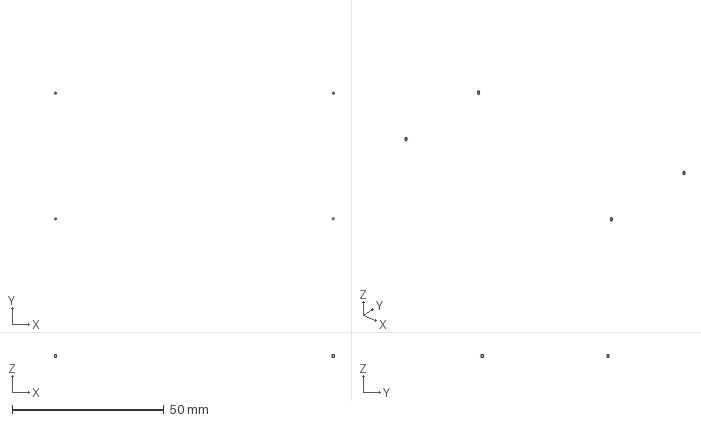
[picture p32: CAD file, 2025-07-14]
hardware/fabrication/control_sync.FCStd
92.3 x 42.1 x 1.00 mm

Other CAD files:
hardware/fabrication/control_fu.FCStd
hardware/fabrication/control_bu.stl
hardware/fabrication/control_fu.stl
hardware/fabrication/control_sync.stl

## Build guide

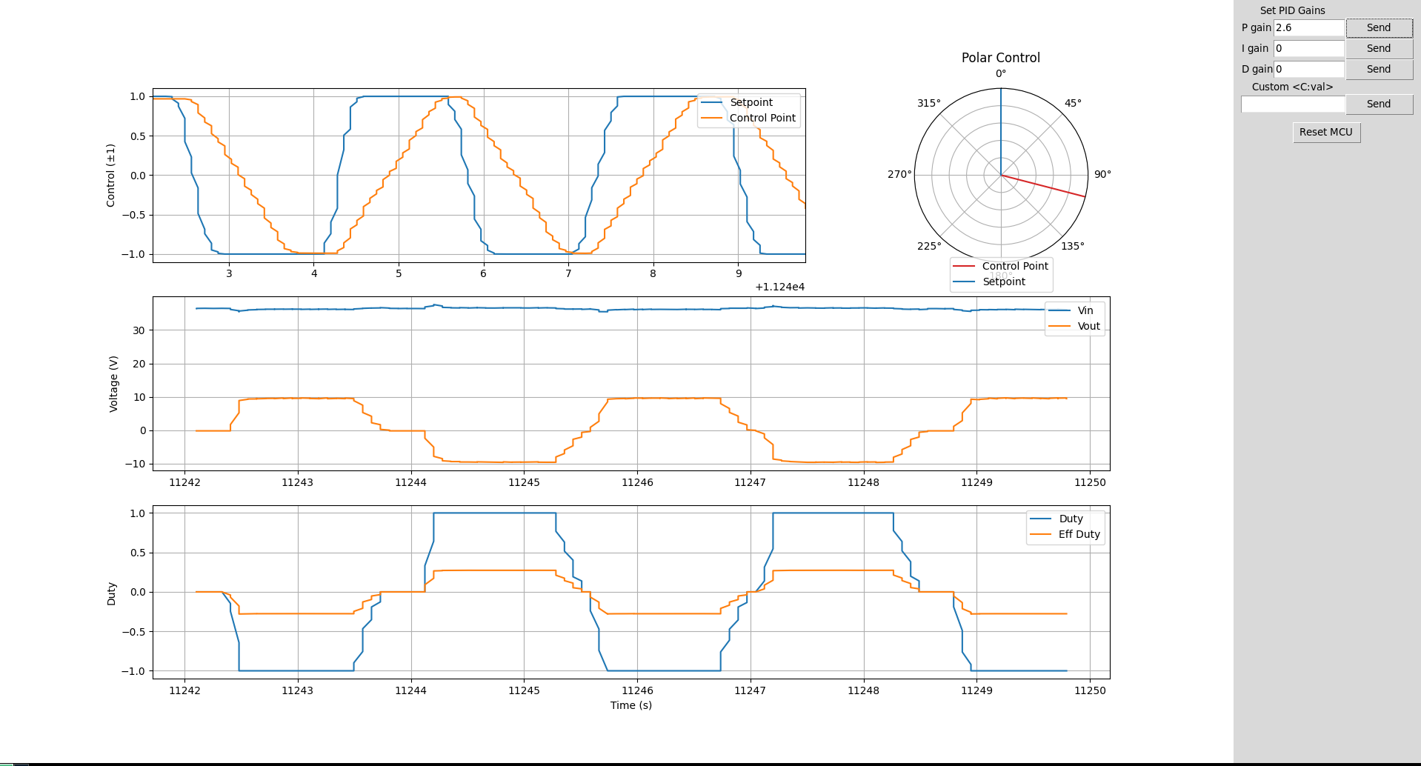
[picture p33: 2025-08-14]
assets/full_accell_step.png

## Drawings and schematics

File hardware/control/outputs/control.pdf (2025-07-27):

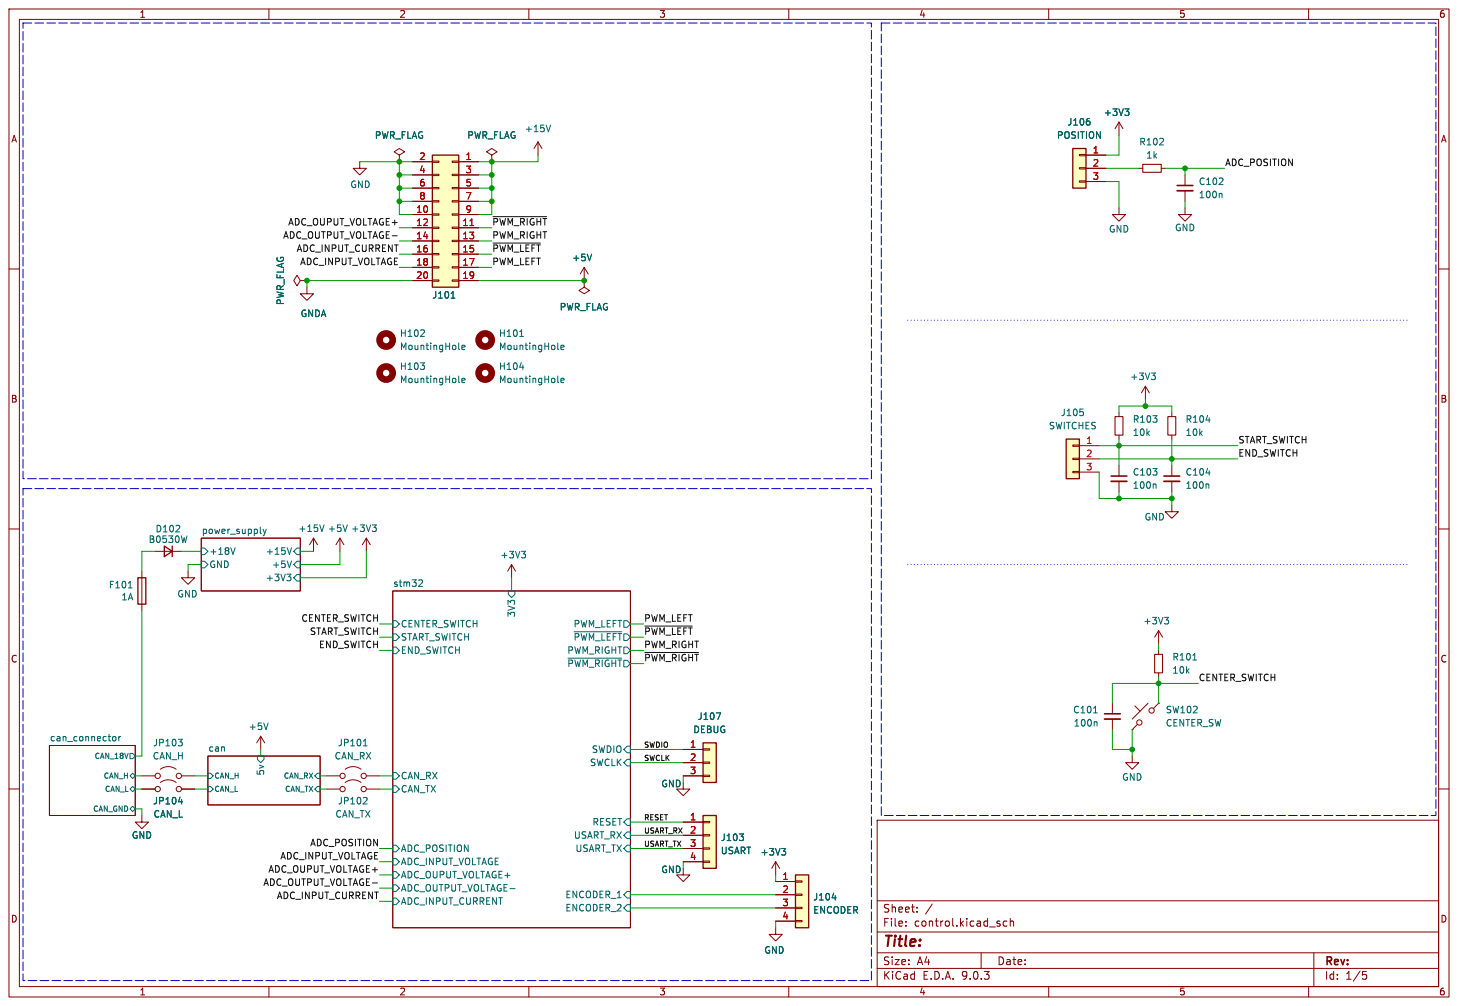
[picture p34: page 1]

Id: 1/5 Title: File: control.kicad_sch Sheet: / CAN_GND

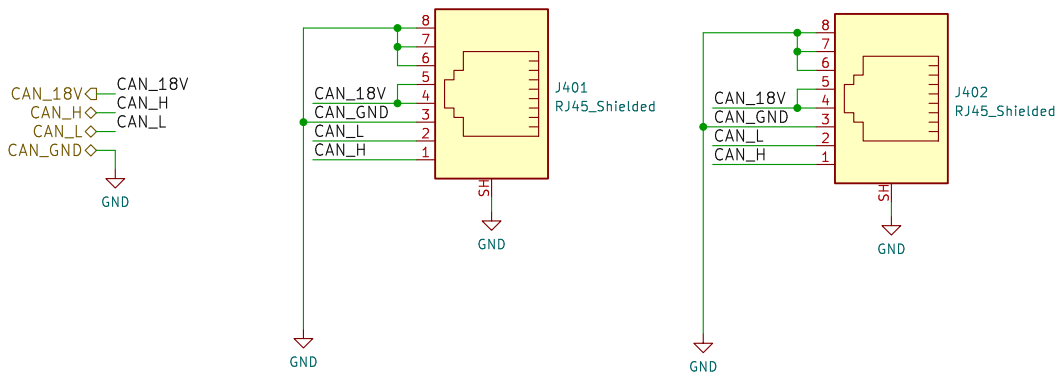
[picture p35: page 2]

Id: 4/5 Title: CAN Connector File: can_connector.kicad_sch Sheet: /can_connector/ Zenite Solar GND SH

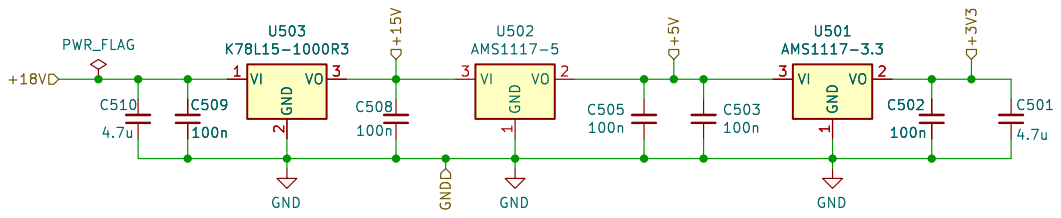
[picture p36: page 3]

File: power_supply.kicad_sch Sheet: /power_supply/ Zenite Solar GND

Id: 5/5 Title: Power Supplies

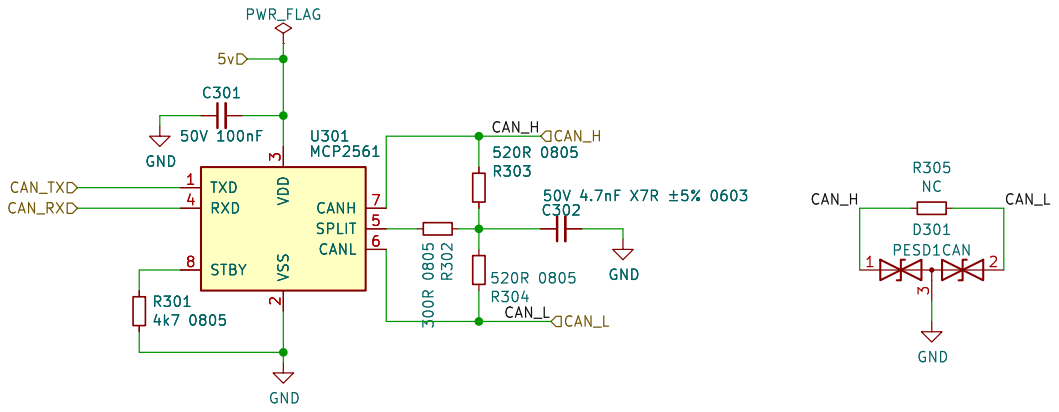
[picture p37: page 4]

CAN_H
50V 4.7nF X7R þÿ±5%0603 GND
File: can.kicad_sch Sheet: /can/ Zenite Solar C302

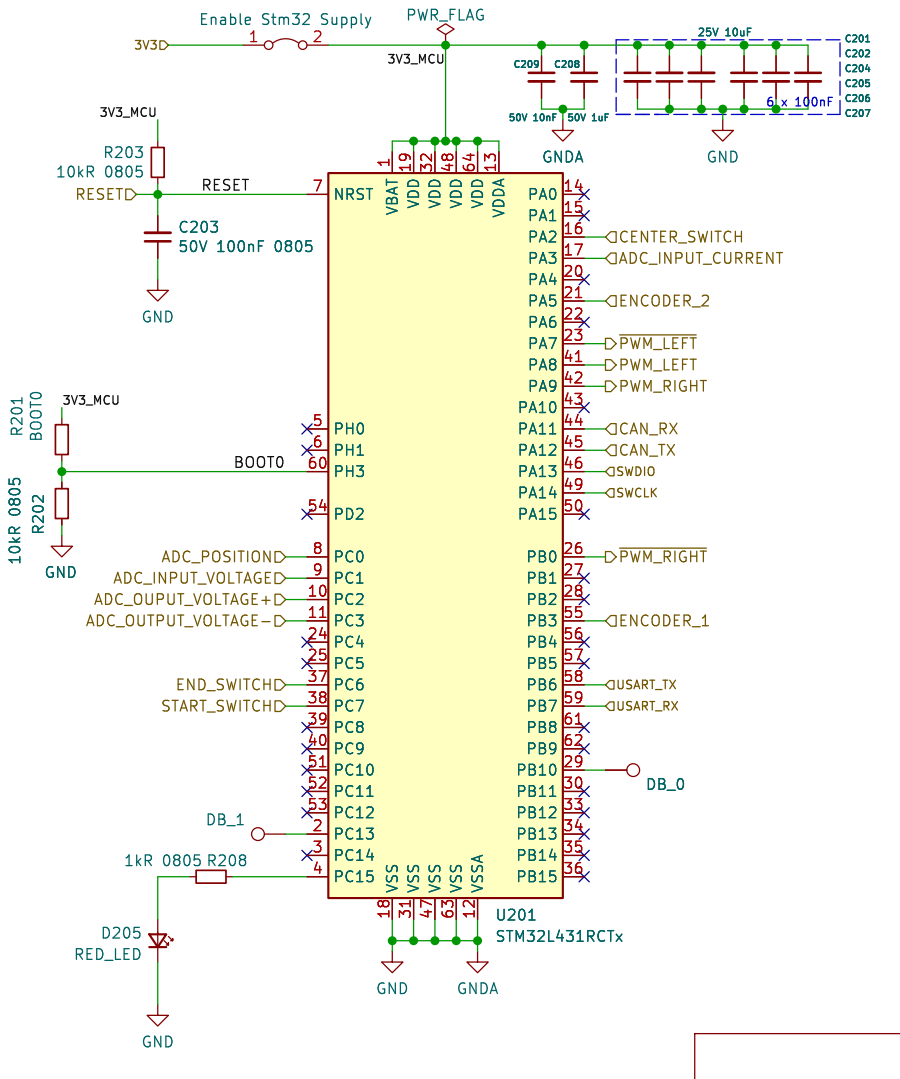
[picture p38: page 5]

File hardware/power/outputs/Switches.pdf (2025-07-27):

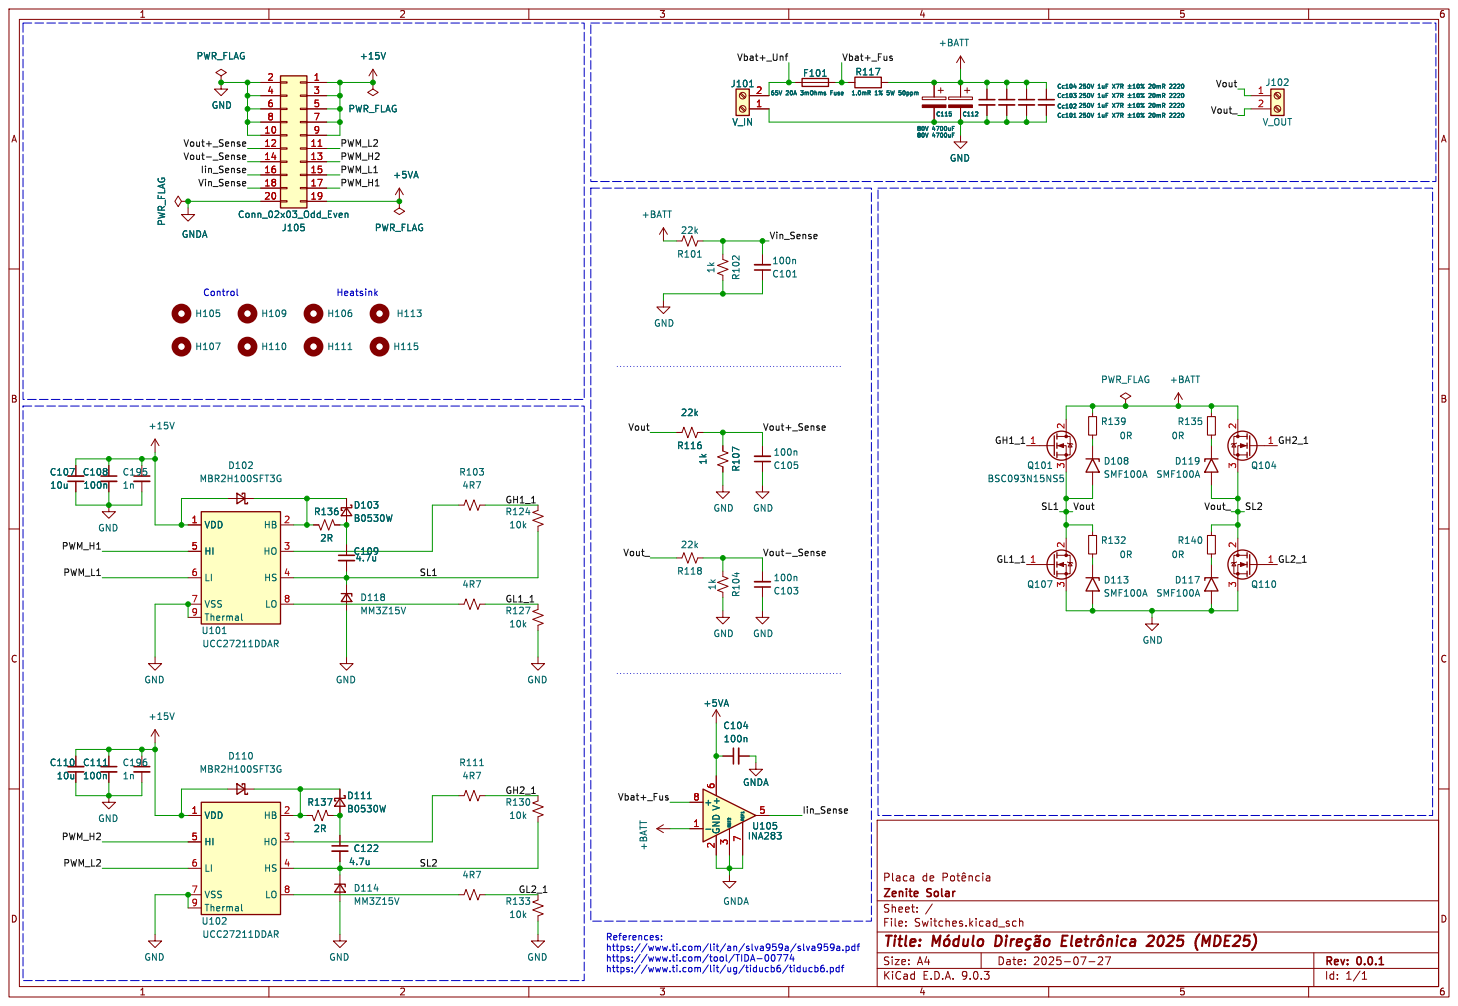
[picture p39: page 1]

Cc102 250V 1uF X7R þÿ±10%20mR 2220 Cc101 250V 1uF X7R þÿ±10%20mR 2220 Cc103 250V 1uF X7R þÿ±10%20mR 2220 Cc104 250V 1uF X7R þÿ±10%20mR 2220 GND

References: https://www.ti.com/lit/an/slva959a/slva959a.pdf

https://www.ti.com/tool/TIDA-00774
https://www.ti.com/lit/ug/tiducb6/tiducb6.pdf

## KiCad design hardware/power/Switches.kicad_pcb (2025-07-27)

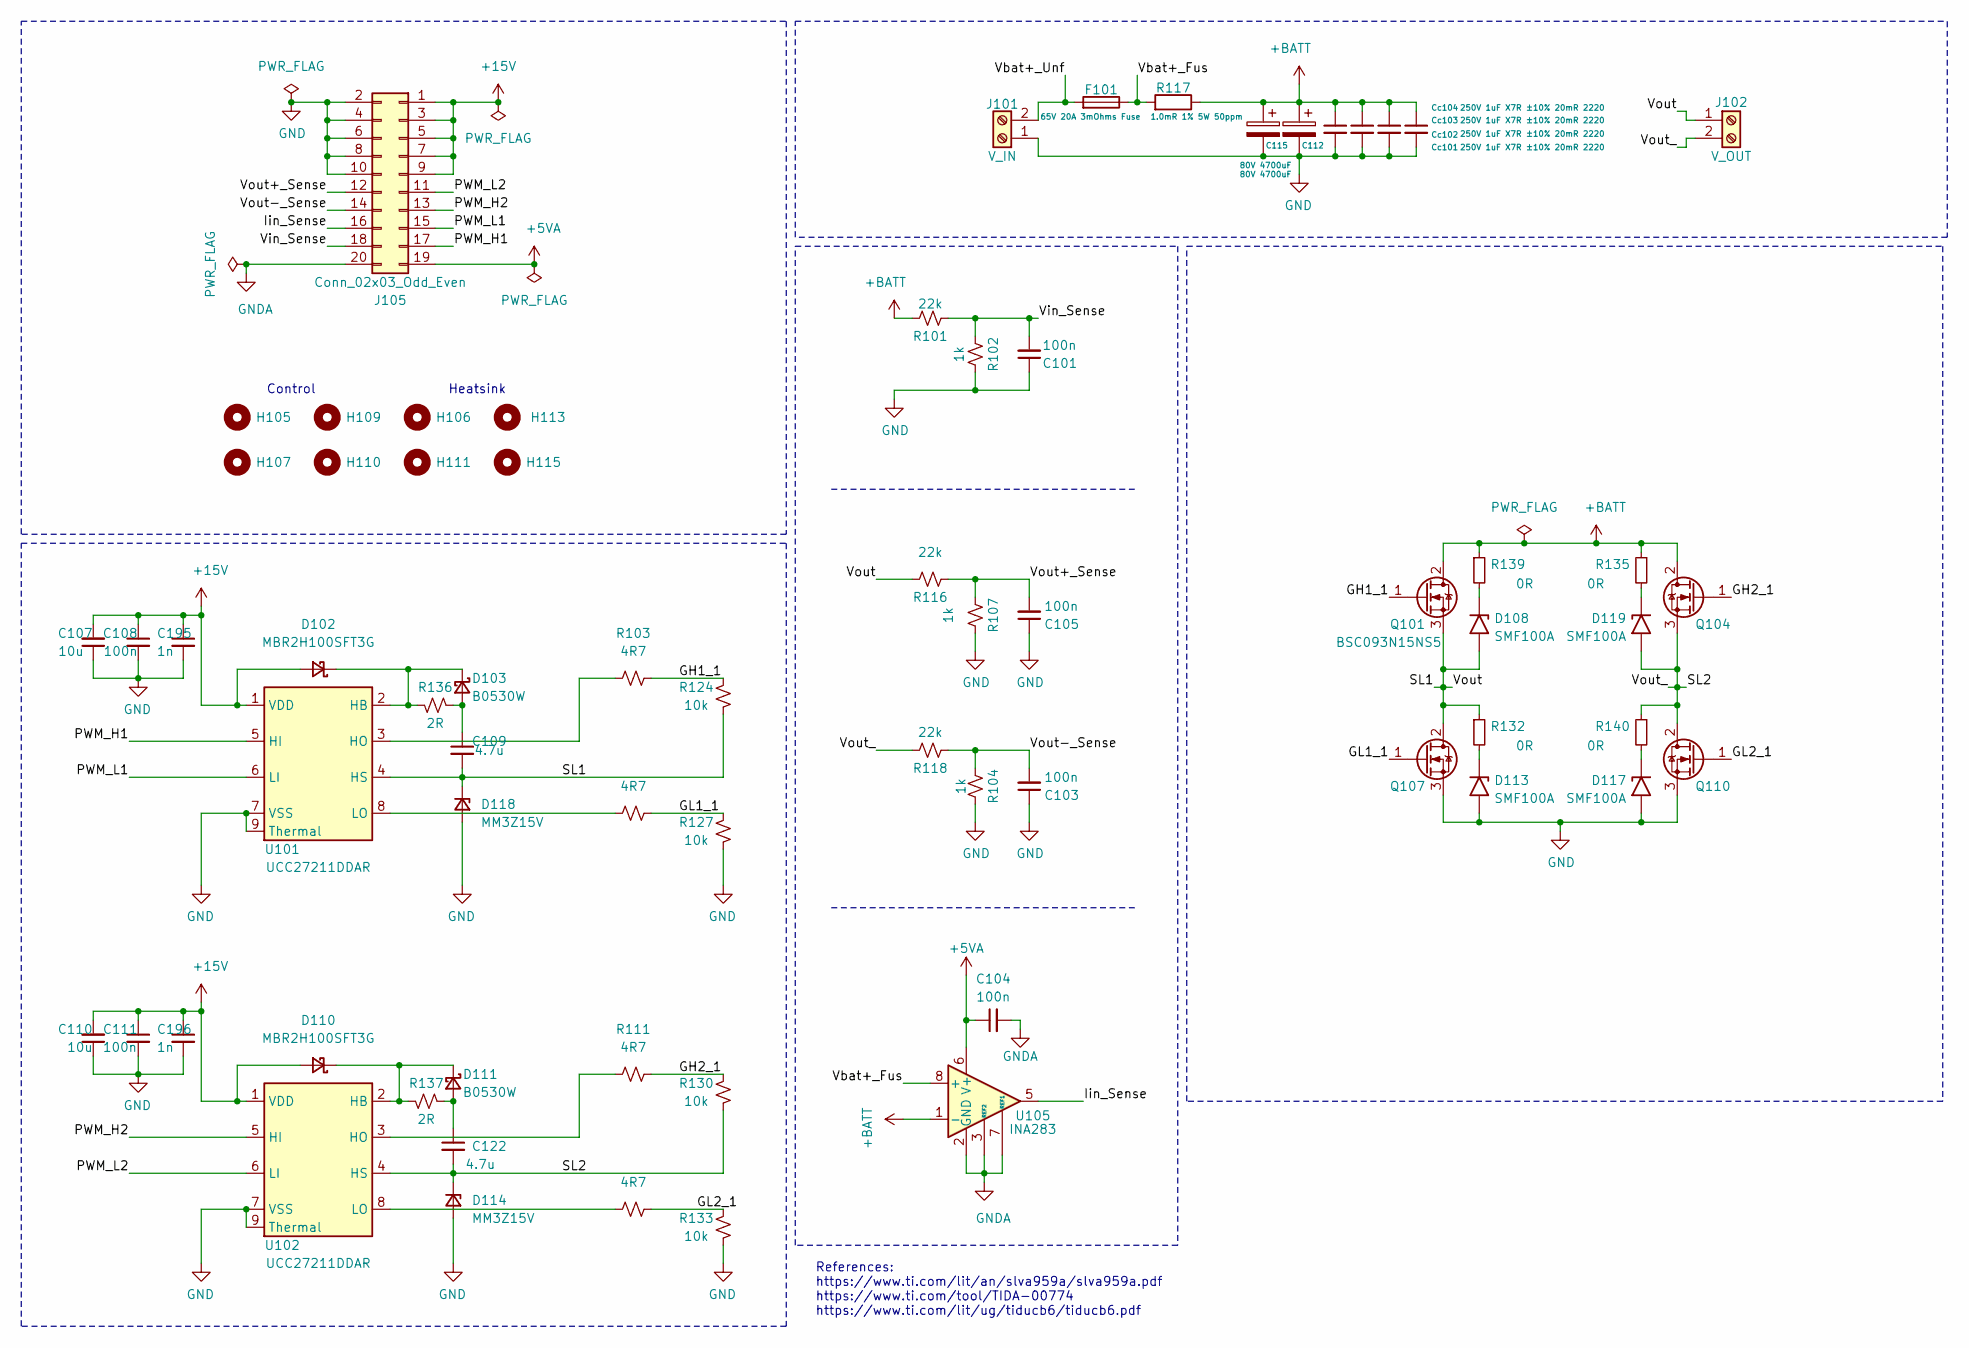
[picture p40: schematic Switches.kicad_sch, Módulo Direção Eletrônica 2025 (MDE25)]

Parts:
C101, C103, C104, C105, C108, C111: 100n; C_0805_2012Metric_Pad1.18x1.45mm_HandSolder
C107, C110: 10u; C_1210_3225Metric_Pad1.33x2.70mm_HandSolder
C109, C122: 4.7u; C_1210_3225Metric_Pad1.33x2.70mm_HandSolder
C112, C115: 80V 4700uF; CP_Radial_D12.5mm_P5.00mm
C195, C196: 1n; C_0805_2012Metric_Pad1.18x1.45mm_HandSolder
Cc101, Cc102, Cc103, Cc104: 250V 1uF X7R ±10% 20mR 2220; C_2220_5650Metric
D102, D110: MBR2H100SFT3G; D_SOD-123F
D103, D111: B0530W; D_SOD-123F
D108, D113, D117, D119: SMF100A; D_SOD-123F
D114, D118: MM3Z15V; D_SOD-123F
F101: 65V 20A 3mOhms Fuse; S6125-F
H105, H106, H107, H109, H110, H111, H113, H115: MountingHole; MountingHole_3.5mm_Pad
J101: V_IN; TerminalBlock_MaiXu_MX126-5.0-02P_1x02_P5.00mm
J102: V_OUT; TerminalBlock_MaiXu_MX126-5.0-02P_1x02_P5.00mm
J105: Conn_02x03_Odd_Even; PinHeader_2x10_P2.54mm_Vertical
Q101, Q104, Q107, Q110: BSC093N15NS5; TDSON-8-3
R101, R116, R118: 22k; R_0805_2012Metric_Pad1.20x1.40mm_HandSolder
R102, R104, R107: 1k; R_0805_2012Metric_Pad1.20x1.40mm_HandSolder
R103, R106, R111, R114: 4R7; R_0805_2012Metric_Pad1.20x1.40mm_HandSolder
R117: 1.0mR 1% 5W 50ppm; R_2512_6332Metric_Pad1.40x3.35mm_HandSolder
R124, R127, R130, R133: 10k; R_0805_2012Metric_Pad1.20x1.40mm_HandSolder
R132, R135, R139, R140: 0R; R_0805_2012Metric_Pad1.20x1.40mm_HandSolder
R136, R137: 2R; R_0805_2012Metric_Pad1.20x1.40mm_HandSolder
U101, U102: UCC27211DDAR; SOIC-8-1EP_3.9x4.9mm_P1.27mm_EP2.514x3.2mm
U105: INA283; SOIC-8_3.9x4.9mm_P1.27mm

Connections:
+5VA: C104.1, J105.19, U105.6 (V+)
+15V: C107.2, C108.1, C110.2, C111.1, C195.1, C196.1, D102.2 (A), D110.2 (A), J105.1, J105.3, J105.5, J105.7, J105.9, U101.1 (VDD), U102.1 (VDD)
+BATT: C112.1, C115.1, Cc101.1, Cc102.1, Cc103.1, Cc104.1, Q101.2 (D), Q104.2 (D), R101.2, R117.1, R135.1, R139.1, U105.1 (-)
/GH1_1: Q101.1 (G), R103.1, R124.2
/GH2_1: Q104.1 (G), R111.1, R130.2
/GL1_1: Q107.1 (G), R106.1, R127.2
/GL2_1: Q110.1 (G), R114.1, R133.2
/Iin_Sense: J105.16, U105.5
/PWM_H1: J105.17, U101.5 (HI)
/PWM_H2: J105.13, U102.5 (HI)
/PWM_L1: J105.15, U101.6 (LI)
/PWM_L2: J105.11, U102.6 (LI)
/SL1: C109.2, D108.2 (A2), D118.1 (K), J102.1, Q101.3 (S), Q107.2 (D), R116.2, R124.1, R132.1, U101.4 (HS)
/SL2: C122.2, D114.1 (K), D119.2 (A2), J102.2, Q104.3 (S), Q110.2 (D), R118.2, R130.1, R140.1, U102.4 (HS)
/Vbat+_Fus: F101.1, R117.2, U105.8 (+)
/Vbat+_Unf: F101.2, J101.2
/Vin_Sense: C101.2, J105.18, R101.1, R102.1
/Vout+_Sense: C105.2, J105.12, R107.1, R116.1
/Vout-_Sense: C103.2, J105.14, R104.1, R118.1
GND: C101.1, C103.1, C105.1, C107.1, C108.2, C110.1, C111.2, C112.2, C115.2, C195.2, C196.2, Cc101.2, Cc102.2, Cc103.2, Cc104.2, D113.2 (A2), D114.2 (A), D117.2 (A2), D118.2 (A), J101.1, J105.2, J105.4, J105.6, J105.8, J105.10, Q107.3 (S), Q110.3 (S), R102.2, R104.2, R107.2, R127.1, R133.1, U101.7 (VSS), U101.9 (Thermal), U102.7 (VSS), U102.9 (Thermal)
GNDA: C104.2, J105.20, U105.2 (GND), U105.3 (REF2), U105.7 (REF1)
unnamed: D102.1 (K), D103.1 (K), R136.1, U101.2 (HB)
unnamed: C109.1, D103.2 (A), R136.2
unnamed: D108.1 (A1), R139.2
unnamed: D110.1 (K), D111.1 (K), R137.1, U102.2 (HB)
unnamed: C122.1, D111.2 (A), R137.2
unnamed: D113.1 (A1), R132.2
unnamed: D117.1 (A1), R140.2
unnamed: D119.1 (A1), R135.2
unnamed: R103.2, U101.3 (HO)
unnamed: R106.2, U101.8 (LO)
unnamed: R111.2, U102.3 (HO)
unnamed: R114.2, U102.8 (LO)

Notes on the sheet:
Control
References: https://www.ti.com/lit/an/slva959a/slva959a.pdf https://www.ti.com/tool/TIDA-00774 https://www.ti.com/lit/ug/tiducb6/tiducb6.pdf
Heatsink

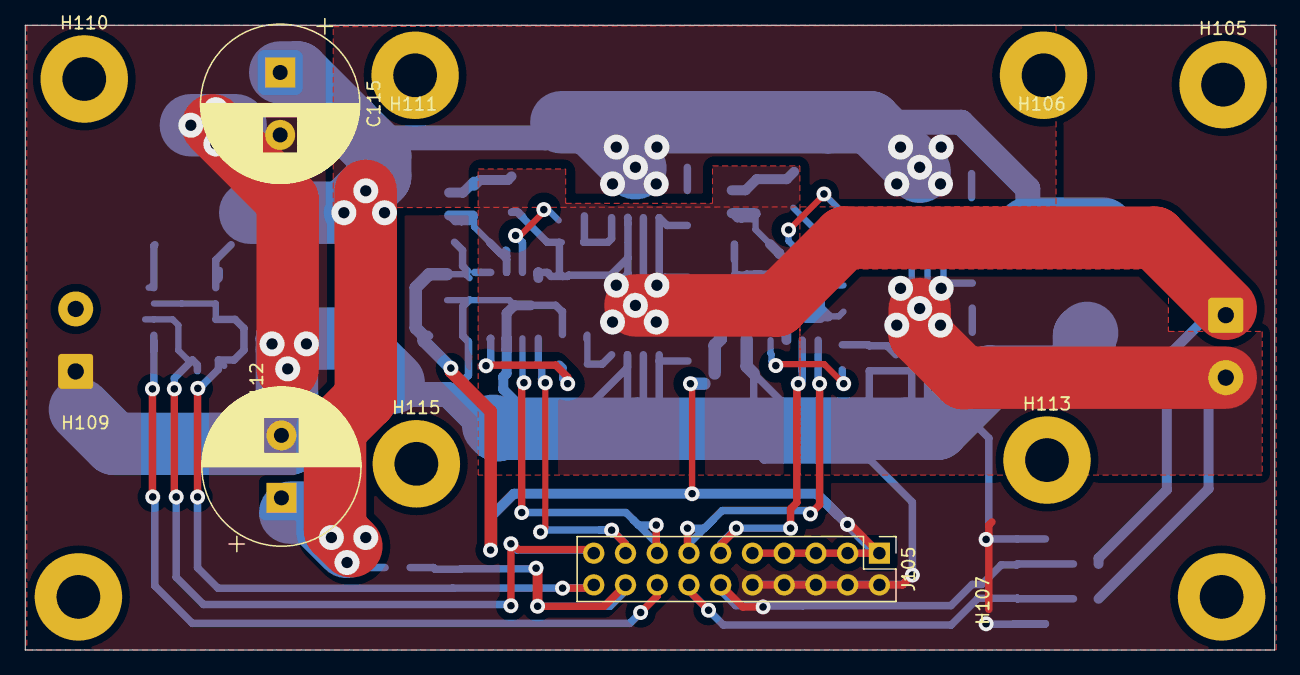
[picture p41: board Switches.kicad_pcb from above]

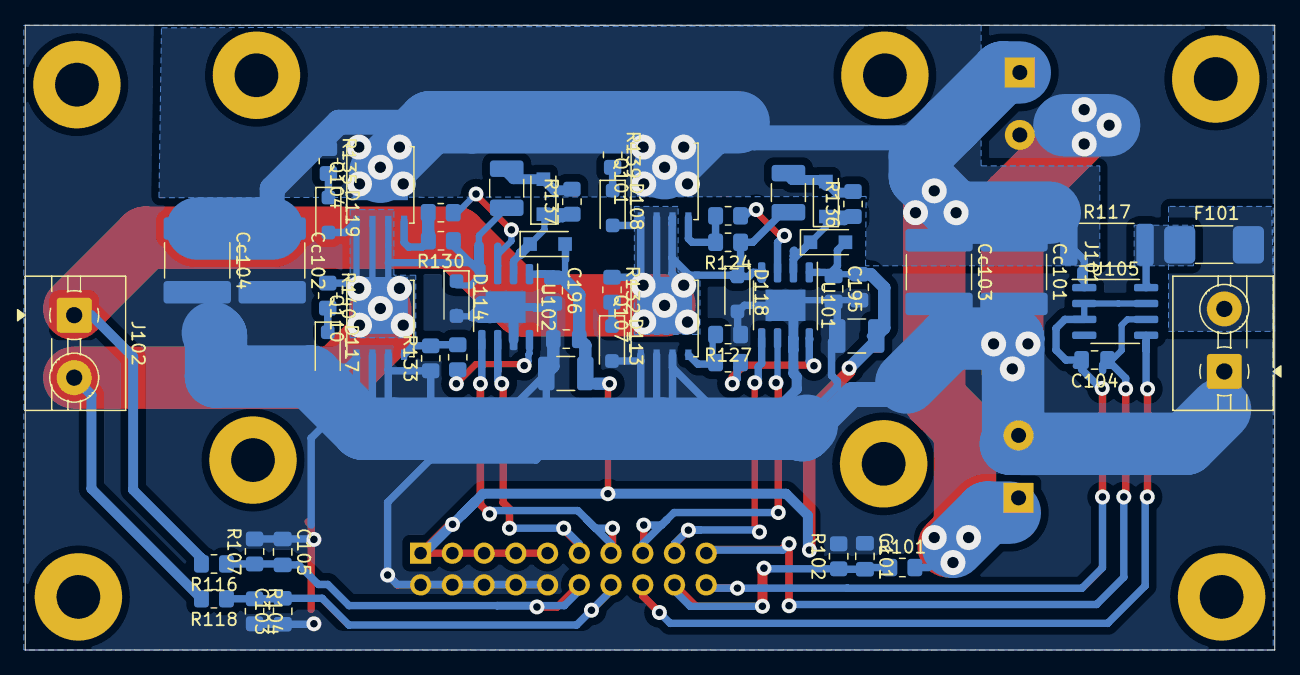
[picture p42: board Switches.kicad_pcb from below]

Board: 2 copper layers, 100.0 x 50.0 mm, 68 parts (57 on the bottom side), 33 nets.

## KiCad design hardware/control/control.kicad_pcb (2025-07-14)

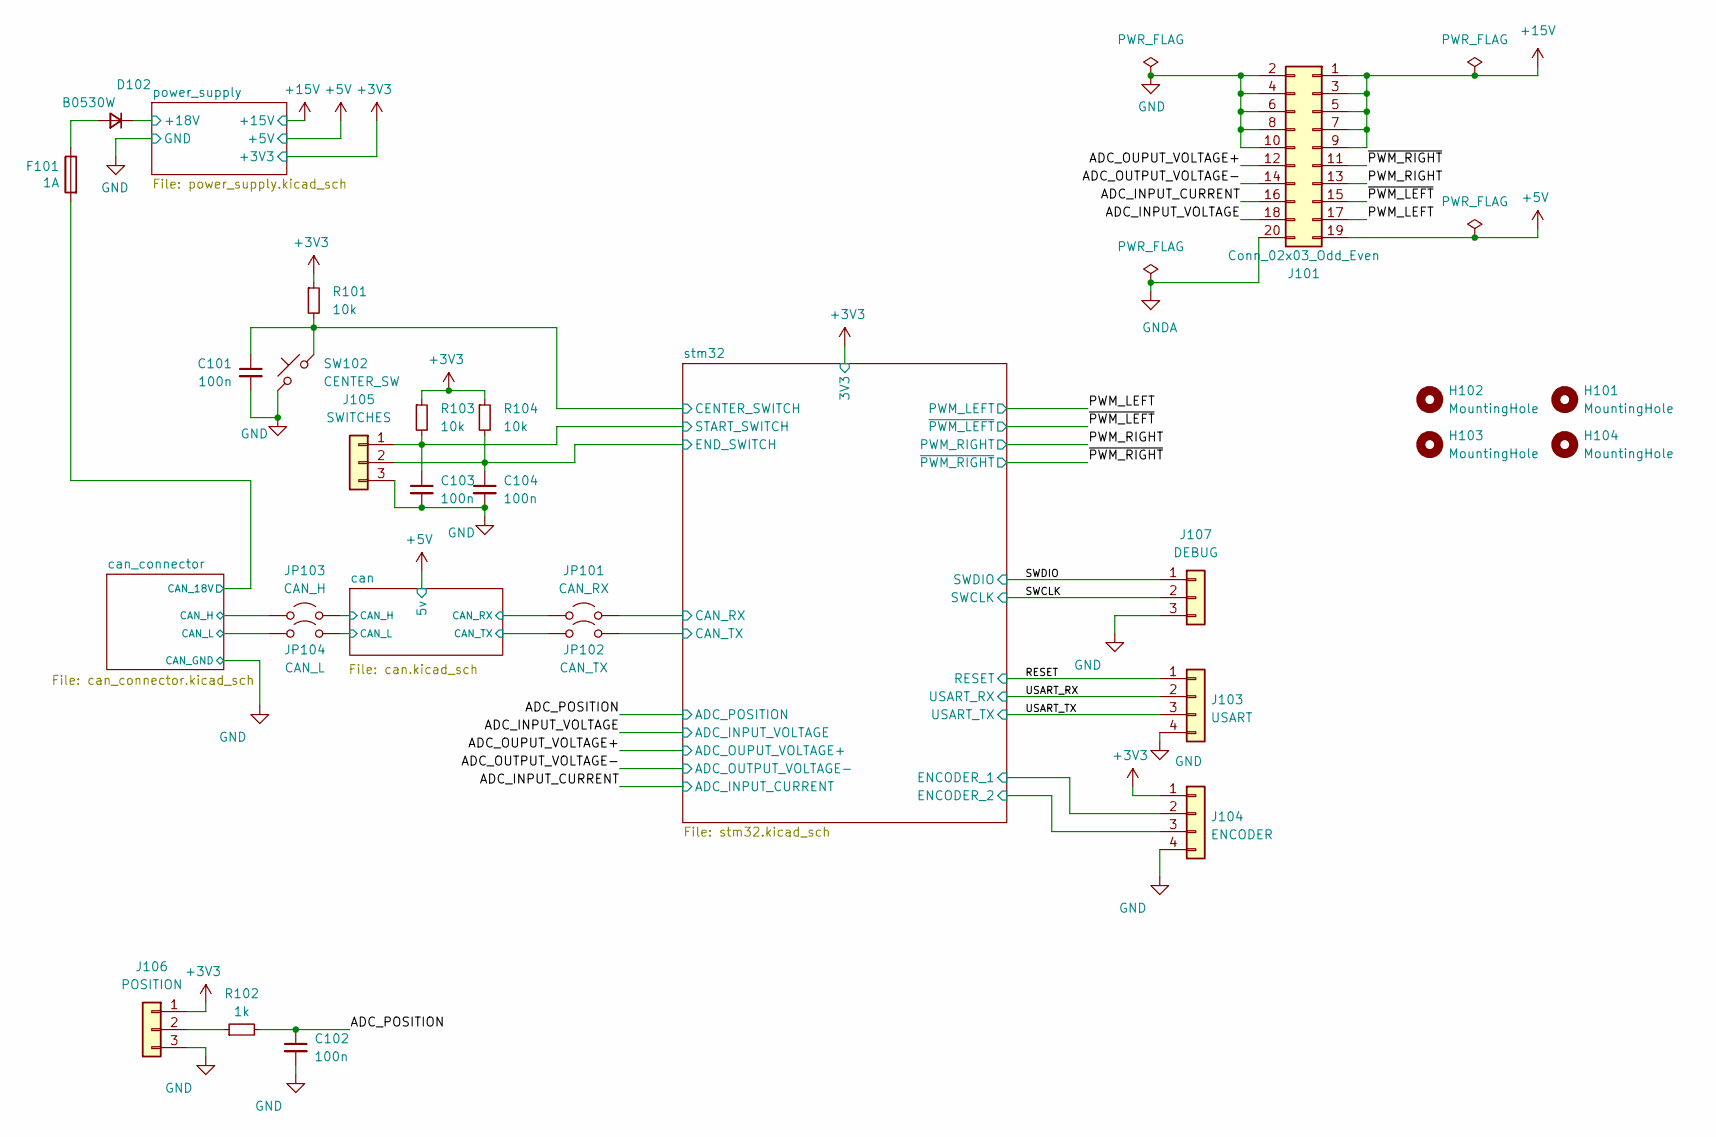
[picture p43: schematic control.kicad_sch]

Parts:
C101, C102, C103, C104: 100n; C_0805_2012Metric_Pad1.18x1.45mm_HandSolder
D102: B0530W; D_SOD-123F
F101: 1A; Fuse_1812_4532Metric_Pad1.30x3.40mm_HandSolder
H101, H102, H103, H104: MountingHole; MountingHole_3.2mm_M3
J101: Conn_02x03_Odd_Even; PinHeader_2x10_P2.54mm_Vertical
J103: USART; PinHeader_1x04_P2.54mm_Vertical
J104: ENCODER; TerminalBlock_bornier-4_P5.08mm
J105: SWITCHES; TerminalBlock_bornier-3_P5.08mm
J106: POSITION; TerminalBlock_bornier-3_P5.08mm
J107: DEBUG; PinHeader_1x03_P2.54mm_Vertical
JP101: CAN_RX; SolderJumper-2_P1.3mm_Open_TrianglePad1.0x1.5mm
JP102: CAN_TX; SolderJumper-2_P1.3mm_Open_TrianglePad1.0x1.5mm
JP103: CAN_H; SolderJumper-2_P1.3mm_Open_TrianglePad1.0x1.5mm
JP104: CAN_L; SolderJumper-2_P1.3mm_Open_TrianglePad1.0x1.5mm
R101, R103, R104: 10k; R_0805_2012Metric_Pad1.20x1.40mm_HandSolder
R102: 1k; R_0805_2012Metric_Pad1.20x1.40mm_HandSolder
SW102: CENTER_SW; SW_PUSH_6mm

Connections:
+3V3: J104.1, J106.1, R101.1, R103.1, R104.1; also elsewhere on the board
+5V: J101.19; also elsewhere on the board
+15V: J101.1, J101.3, J101.5, J101.7, J101.9; also elsewhere on the board
/ADC_INPUT_CURRENT: J101.16; also elsewhere on the board
/ADC_INPUT_VOLTAGE: J101.18; also elsewhere on the board
/ADC_OUPUT_VOLTAGE+: J101.12; also elsewhere on the board
/ADC_OUTPUT_VOLTAGE-: J101.14; also elsewhere on the board
/ADC_POSITION: C102.1, R102.2; also elsewhere on the board
/PWM_LEFT: J101.17; also elsewhere on the board
/PWM_RIGHT: J101.13; also elsewhere on the board
/RESET: J103.1; also elsewhere on the board
/SWCLK: J107.2; also elsewhere on the board
/SWDIO: J107.1; also elsewhere on the board
/USART_RX: J103.2; also elsewhere on the board
/USART_TX: J103.3; also elsewhere on the board
/can/CAN_H: JP103.1 (A); also elsewhere on the board
/can/CAN_L: JP104.1 (A); also elsewhere on the board
/can/CAN_RX: JP101.2 (B); also elsewhere on the board
/can/CAN_TX: JP102.2 (B); also elsewhere on the board
/can_connector/CAN_18V: F101.2; also elsewhere on the board
/can_connector/CAN_H: JP103.2 (B); also elsewhere on the board
/can_connector/CAN_L: JP104.2 (B); also elsewhere on the board
/power_supply/+18V: D102.1 (K); also elsewhere on the board
/stm32/CAN_RX: JP101.1 (A); also elsewhere on the board
/stm32/CAN_TX: JP102.1 (A); also elsewhere on the board
/stm32/CENTER_SWITCH: C101.1, R101.2, SW102.2; also elsewhere on the board
/stm32/ENCODER_1: J104.2; also elsewhere on the board
/stm32/ENCODER_2: J104.3; also elsewhere on the board
/stm32/END_SWITCH: C104.1, J105.2, R104.2; also elsewhere on the board
/stm32/START_SWITCH: C103.1, J105.1, R103.2; also elsewhere on the board
/~PWM_LEFT: J101.15; also elsewhere on the board
/~PWM_RIGHT: J101.11; also elsewhere on the board
GND: C101.2, C102.2, C103.2, C104.2, J101.2, J101.4, J101.6, J101.8, J101.10, J101.20, J103.4, J104.4, J105.3, J106.3, J107.3, SW102.1; also elsewhere on the board
unnamed: D102.2 (A), F101.1
unnamed: J106.2, R102.1

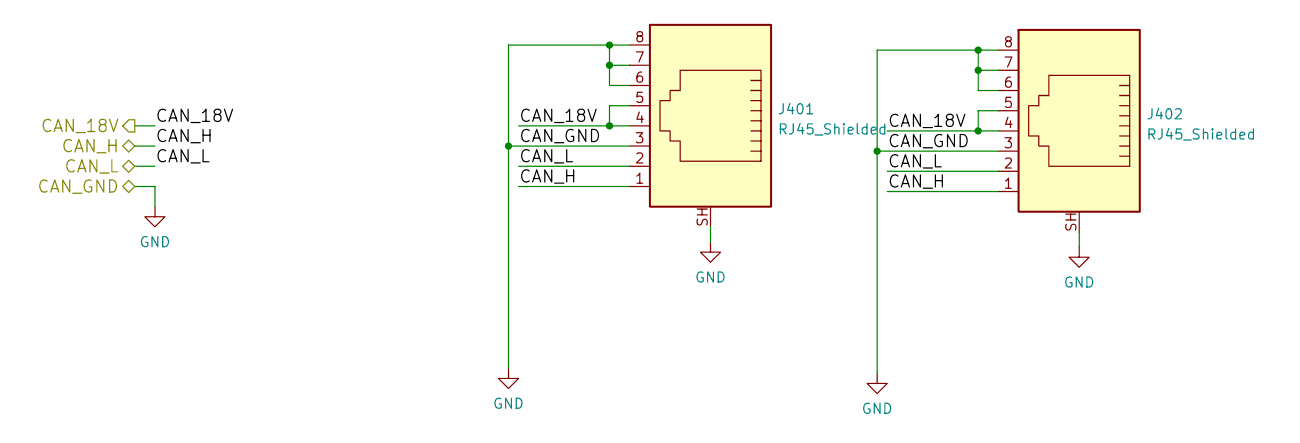
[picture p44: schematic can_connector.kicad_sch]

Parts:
J401, J402: RJ45_Shielded; RJ45_YH59_01

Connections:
/can_connector/CAN_18V: J401.4, J401.5, J402.4, J402.5; also elsewhere on the board
/can_connector/CAN_H: J401.1, J402.1; also elsewhere on the board
/can_connector/CAN_L: J401.2, J402.2; also elsewhere on the board
GND: J401.3, J401.6, J401.7, J401.8, J401.SH, J402.3, J402.6, J402.7, J402.8, J402.SH; also elsewhere on the board

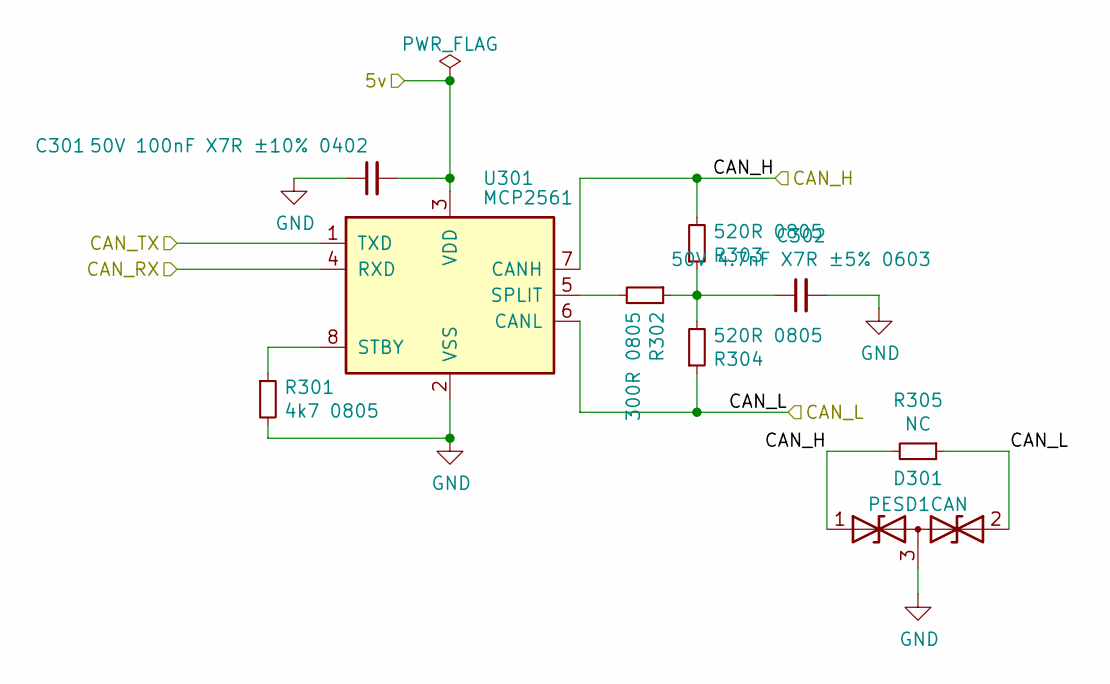
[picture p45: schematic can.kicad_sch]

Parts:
C301: 50V 100nF X7R ±10% 0402; C_0805_2012Metric_Pad1.18x1.45mm_HandSolder
C302: 50V 4.7nF X7R ±5% 0603; C_0805_2012Metric_Pad1.18x1.45mm_HandSolder
D301: PESD1CAN; SOT-23_Handsoldering
R301: 4k7 0805; R_0805_2012Metric_Pad1.20x1.40mm_HandSolder
R302: 300R 0805; R_0805_2012Metric_Pad1.20x1.40mm_HandSolder
R303, R304: 520R 0805; R_0805_2012Metric_Pad1.20x1.40mm_HandSolder
R305: NC; R_0805_2012Metric_Pad1.20x1.40mm_HandSolder
U301: MCP2561; SOIC-8_3.9x4.9mm_P1.27mm

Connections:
+5V: C301.2, U301.3 (VDD); also elsewhere on the board
/can/CAN_H: D301.1 (A1), R303.2, R305.2, U301.7 (CANH); also elsewhere on the board
/can/CAN_L: D301.2 (A2), R304.1, R305.1, U301.6 (CANL); also elsewhere on the board
/can/CAN_RX: U301.4 (RXD); also elsewhere on the board
/can/CAN_TX: U301.1 (TXD); also elsewhere on the board
GND: C301.1, C302.2, D301.3 (common), R301.2, U301.2 (VSS); also elsewhere on the board
unnamed: C302.1, R302.1, R303.1, R304.2
unnamed: R302.2, U301.5 (SPLIT)
unnamed: R301.1, U301.8 (STBY)

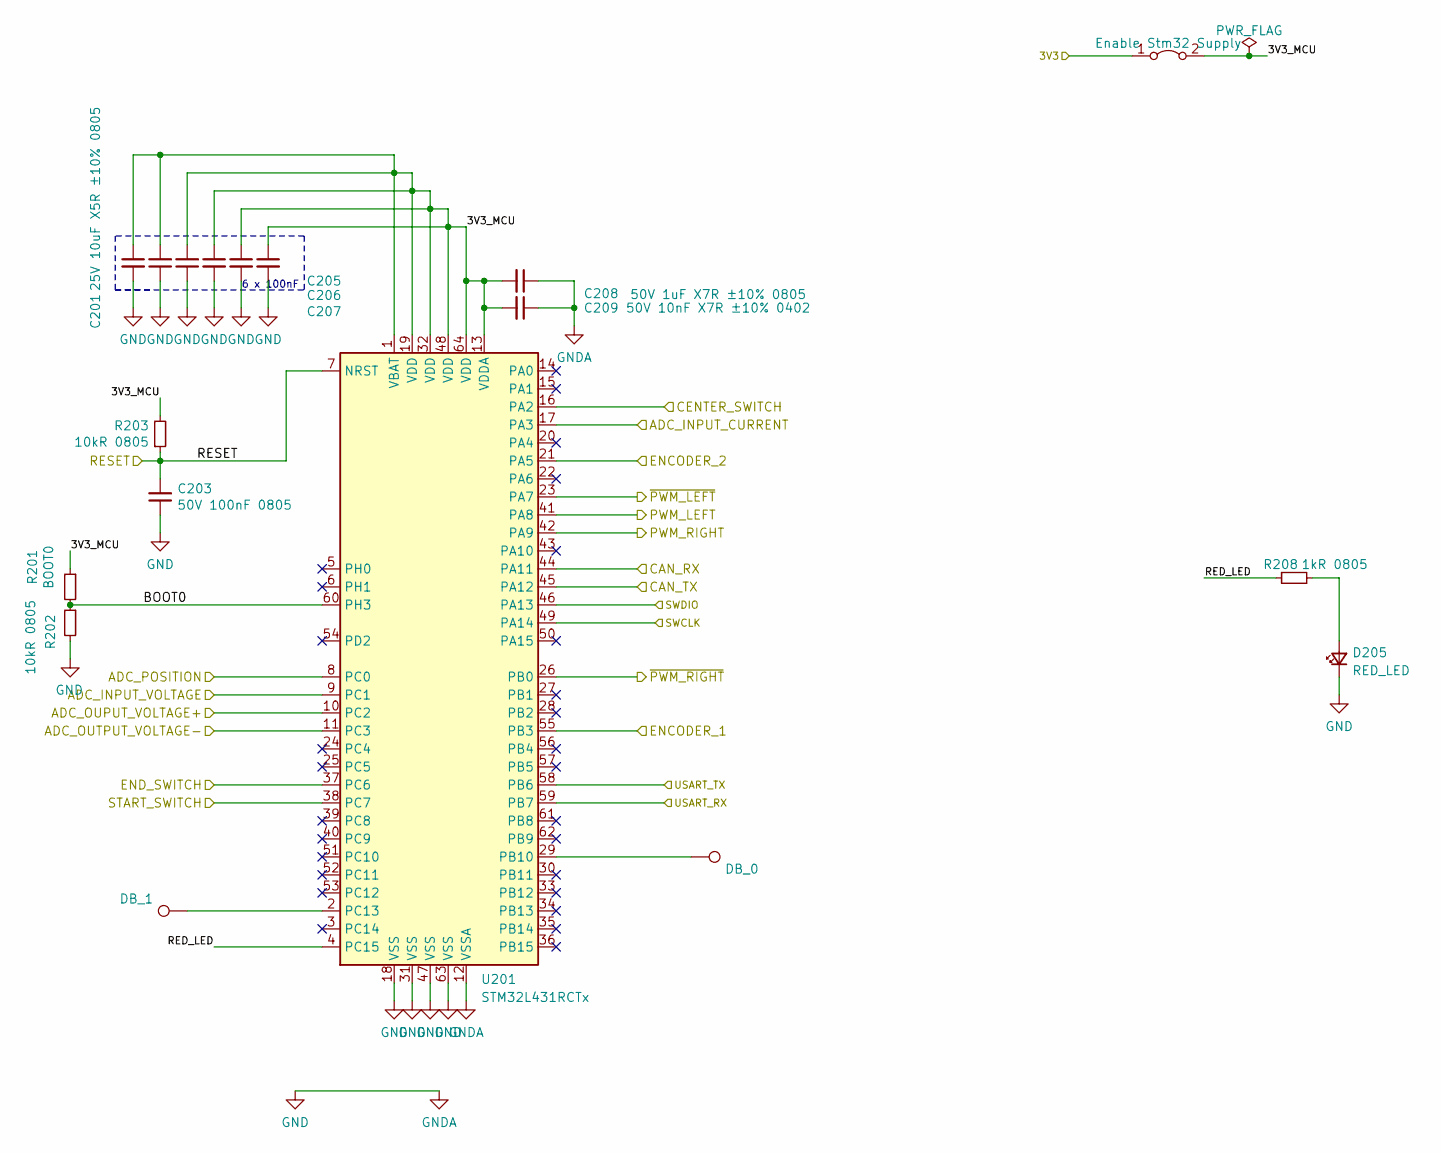
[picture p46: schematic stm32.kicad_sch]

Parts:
C201: 25V 10uF X5R ±10% 0805; C_0805_2012Metric_Pad1.18x1.45mm_HandSolder
C202, C203, C204: 50V 100nF 0805; C_0805_2012Metric_Pad1.18x1.45mm_HandSolder
C205, C206, C207: 50V 100nF X7R ±10% 0402; C_0805_2012Metric_Pad1.18x1.45mm_HandSolder
C208: 50V 1uF X7R ±10% 0805; C_0805_2012Metric_Pad1.18x1.45mm_HandSolder
C209: 50V 10nF X7R ±10% 0402; C_0805_2012Metric_Pad1.18x1.45mm_HandSolder
D205: RED_LED; LED_0805_2012Metric_Pad1.15x1.40mm_HandSolder
JP205: Enable Stm32 Supply; SolderJumper-2_P1.3mm_Open_TrianglePad1.0x1.5mm
R201: BOOT0; R_0805_2012Metric_Pad1.20x1.40mm_HandSolder
R202, R203: 10kR 0805; R_0805_2012Metric_Pad1.20x1.40mm_HandSolder
R208: 1kR 0805; R_0805_2012Metric_Pad1.20x1.40mm_HandSolder
TP202: DB_1; TestPoint_Pad_1.0x1.0mm
TP203: DB_0; TestPoint_Pad_1.0x1.0mm
U201: STM32L431RCTx; LQFP-64_10x10mm_P0.5mm

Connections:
+3V3: JP205.1 (A); also elsewhere on the board
/ADC_INPUT_CURRENT: U201.17 (PA3); also elsewhere on the board
/ADC_INPUT_VOLTAGE: U201.9 (PC1); also elsewhere on the board
/ADC_OUPUT_VOLTAGE+: U201.10 (PC2); also elsewhere on the board
/ADC_OUTPUT_VOLTAGE-: U201.11 (PC3); also elsewhere on the board
/ADC_POSITION: U201.8 (PC0); also elsewhere on the board
/PWM_LEFT: U201.41 (PA8); also elsewhere on the board
/PWM_RIGHT: U201.42 (PA9); also elsewhere on the board
/RESET: C203.2, R203.1, U201.7 (NRST); also elsewhere on the board
/SWCLK: U201.49 (PA14); also elsewhere on the board
/SWDIO: U201.46 (PA13); also elsewhere on the board
/USART_RX: U201.59 (PB7); also elsewhere on the board
/USART_TX: U201.58 (PB6); also elsewhere on the board
/stm32/3V3_MCU: C201.1, C202.2, C204.2, C205.1, C206.1, C207.1, C208.2, C209.2, JP205.2 (B), R201.1, R203.2, U201.1 (VBAT), U201.13 (VDDA), U201.19 (VDD), U201.32 (VDD), U201.48 (VDD), U201.64 (VDD)
/stm32/BOOT0: R201.2, R202.1, U201.60 (PH3)
/stm32/CAN_RX: U201.44 (PA11); also elsewhere on the board
/stm32/CAN_TX: U201.45 (PA12); also elsewhere on the board
/stm32/CENTER_SWITCH: U201.16 (PA2); also elsewhere on the board
/stm32/ENCODER_1: U201.55 (PB3); also elsewhere on the board
/stm32/ENCODER_2: U201.21 (PA5); also elsewhere on the board
/stm32/END_SWITCH: U201.37 (PC6); also elsewhere on the board
/stm32/RED_LED: R208.1, U201.4 (PC15)
/stm32/START_SWITCH: U201.38 (PC7); also elsewhere on the board
/~PWM_LEFT: U201.23 (PA7); also elsewhere on the board
/~PWM_RIGHT: U201.26 (PB0); also elsewhere on the board
GND: C201.2, C202.1, C203.1, C204.1, C205.2, C206.2, C207.2, C208.1, C209.1, D205.1 (K), R202.2, U201.12 (VSSA), U201.18 (VSS), U201.31 (VSS), U201.47 (VSS), U201.63 (VSS); also elsewhere on the board
unnamed: D205.2 (A), R208.2
unnamed: TP203.1, U201.29 (PB10)
unnamed: TP202.1, U201.2 (PC13)

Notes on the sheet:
6 x 100nF

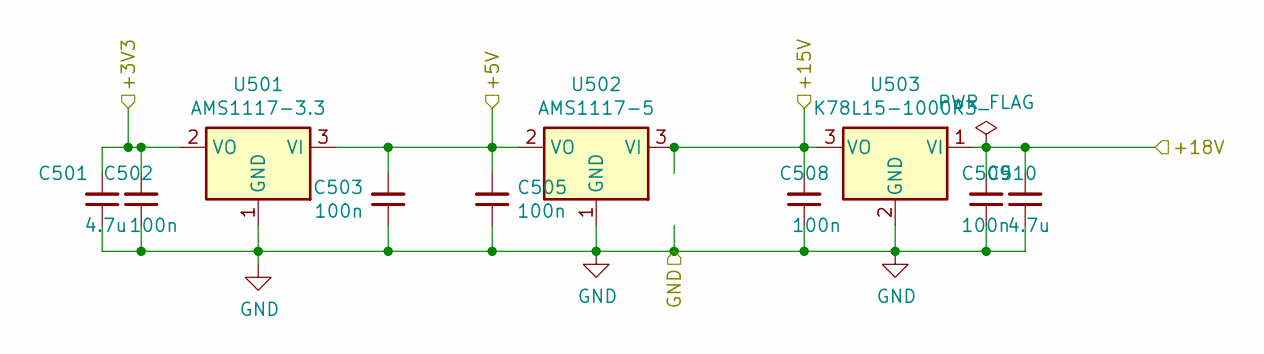
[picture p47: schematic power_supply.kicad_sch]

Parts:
C501, C510: 4.7u; C_1206_3216Metric_Pad1.33x1.80mm_HandSolder
C502, C503, C505, C508, C509: 100n; C_0805_2012Metric_Pad1.18x1.45mm_HandSolder
U501: AMS1117-3.3; SOT-223-3_TabPin2
U502: AMS1117-5; SOT-223-3_TabPin2
U503: K78L15-1000R3; TO-220-3_Horizontal_TabDown_SMD

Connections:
+3V3: C501.2, C502.2, U501.2 (VO); also elsewhere on the board
+5V: C503.2, C505.2, U501.3 (VI), U502.2 (VO); also elsewhere on the board
+15V: C508.2, U502.3 (VI), U503.3 (VO); also elsewhere on the board
/power_supply/+18V: C509.2, C510.2, U503.1 (VI); also elsewhere on the board
GND: C501.1, C502.1, C503.1, C505.1, C508.1, C509.1, C510.1, U501.1 (GND), U502.1 (GND), U503.2 (GND); also elsewhere on the board

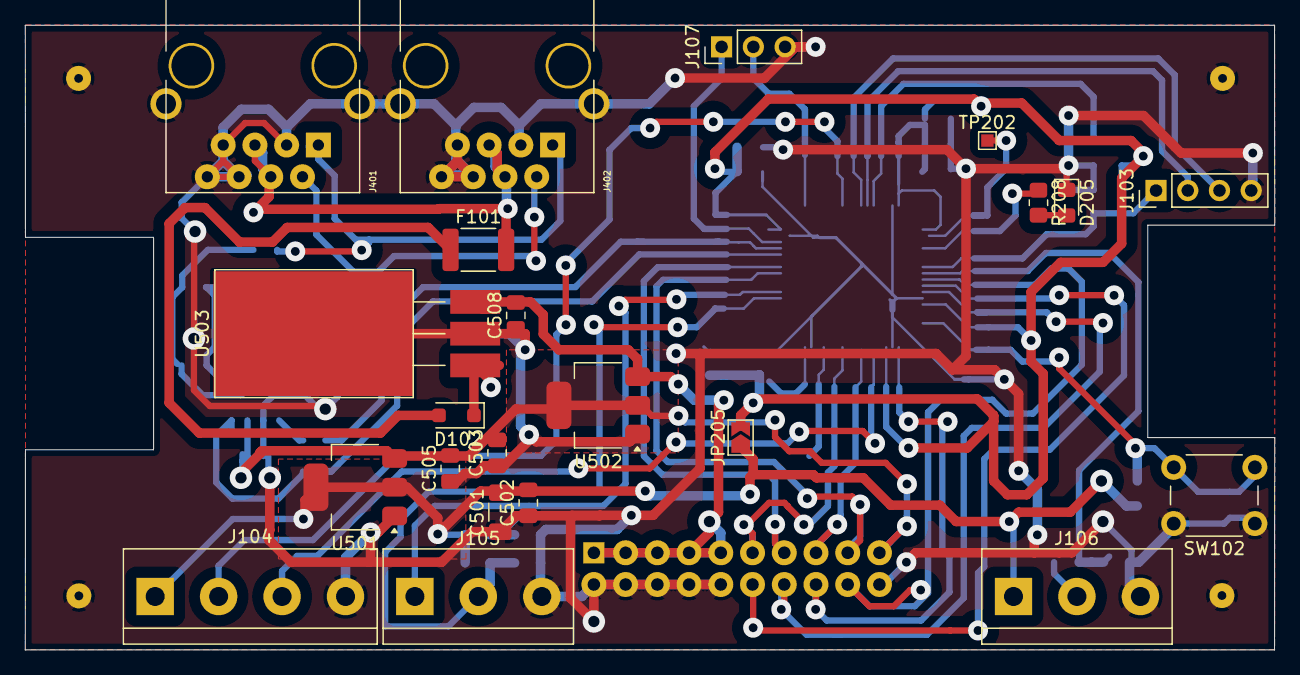
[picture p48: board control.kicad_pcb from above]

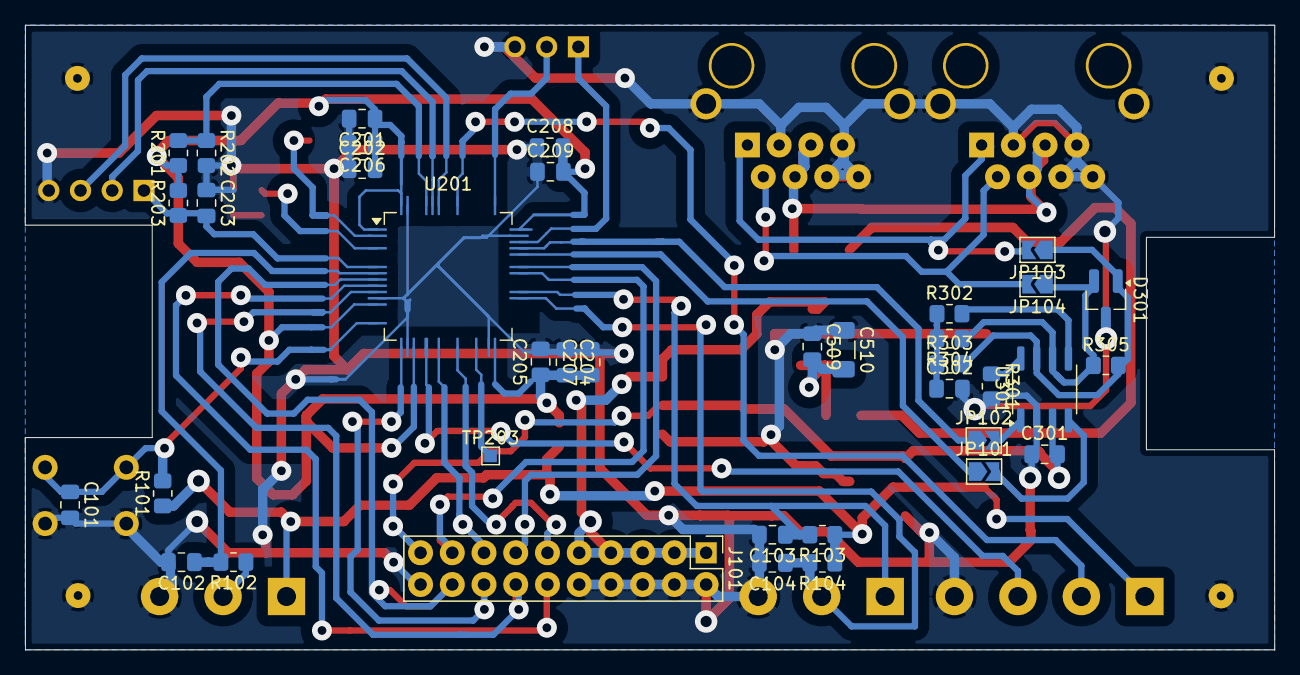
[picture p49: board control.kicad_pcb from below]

Board: 2 copper layers, 100.0 x 50.0 mm, 60 parts (38 on the bottom side), 44 nets.

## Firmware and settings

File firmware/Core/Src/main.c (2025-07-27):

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
/* Includes ------------------------------------------------------------------*/
#include "main.h"
#include "adc.h"
#include "can.h"
#include "dma.h"
#include "tim.h"
#include "usart.h"
#include "gpio.h"

/* USER CODE BEGIN Includes */
#include <stdio.h>

#include "config.h"

#include "Core/pwm.h"
#include "Core/sense.h"
#include "Core/control.h"
#include "Core/uart_server.h"
#include "Core/CAN/can_server.h"
#include "Core/status.h"
#include "Core/telemetry.h"
/* USER CODE END Includes */


void SystemClock_Config(void);
/**
  * @brief  The application entry point.
  * @retval int
  */
int main(void)
{

  /* MCU Configuration--------------------------------------------------------*/

  /* Reset of all peripherals, Initializes the Flash interface and the Systick. */
  HAL_Init();

  /* Configure the system clock */
  SystemClock_Config();

  /* Initialize all configured peripherals */
  MX_GPIO_Init();
  MX_DMA_Init();
  MX_USART1_UART_Init();
  MX_TIM1_Init();
  MX_ADC1_Init();
  MX_TIM2_Init();
  MX_CAN1_Init();
  MX_TIM7_Init();
  MX_TIM6_Init();
  /* USER CODE BEGIN 2 */

  /** Some stabilization delay to avoid fast resets killing driver */
  HAL_Delay(2000);
  pwm_init();
  HAL_Delay(2000);

  sense_init();
  control_init(sense_get_control_point, pwm_set_duty);
  can_server_init(control_set_setpoint, control_reset_setpoint);
  uart_server_init();

  long long last_update_tick = HAL_GetTick();
  /* USER CODE END 2 */

  /* Infinite loop */
  /* USER CODE BEGIN WHILE */
  while (1)
  {
    uart_server_update();
    /* USER CODE END WHILE */

    /* USER CODE BEGIN 3 */
    if (HAL_GetTick() - last_update_tick > TELEMETRY_UPDATE_INTERVAL_MS)
    {
      /** Update telemetry */
      telemetry_update();
      last_update_tick = HAL_GetTick();

      /** Tells user we are alive */
      HAL_GPIO_TogglePin(USER_LED_RED_GPIO_Port, USER_LED_RED_Pin);
    }
  }
  /* USER CODE END 3 */
}

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


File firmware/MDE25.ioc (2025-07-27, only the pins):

Mcu.UserName=STM32L431RCTx
PA11.Signal=CAN1_RX
PA12.Signal=CAN1_TX
PA2.GPIO_Label=USER_BUTTON
PA2.Signal=GPXTI2
PA3.Signal=ADCx_IN8
PA7.Signal=TIM1_CH1N
PA8.Signal=S_TIM1_CH1
PA9.Signal=S_TIM1_CH2
PB0.Signal=TIM1_CH2N
PB10.GPIO_Label=USER_DEBUG_0
PB10.Signal=GPIO_Output
PB6.Signal=USART1_TX
PB7.Signal=USART1_RX
PC0.Signal=ADCx_IN1
PC1.GPIO_Label=INPUT_VOLTAGE
PC1.Signal=ADCx_IN2
PC13.GPIO_Label=USER_DEBUG_1
PC13.Signal=GPIO_Output
PC2.GPIO_Label=OUTPUT_VOLTAGE_P
PC2.Signal=ADCx_IN3
PC3.GPIO_Label=OUTPUT_VOLTAGE_N
PC3.Signal=ADCx_IN4

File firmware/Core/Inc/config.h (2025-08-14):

#ifndef __CONFIG_H__
#define __CONFIG_H__

/**
 * ============================
 * Telemetry
 * ============================
 */

/**
 * @brief Interval used to send new batch of telemetry data to host computer
 */
#define TELEMETRY_UPDATE_INTERVAL_MS 25U

/**
 * @brief Preamble used to identify telemetry data
 */
#define TELEMETRY_PREAMBLE 0x5A54U

/**
 * ============================
 * Debug
 * ============================
 */

#define DEBUG_CONTROL_ENABLE    0U
#define DEBUG_TELEMETRY_ENABLE  1U

/**
 * ============================
 * UART
 * ============================
 */

#define UART_RX_BUFFER_SIZE 128U
#define UART_MAX_MESSAGE_SIZE 64U

/**
 * ============================
 * PWM
 * ============================
 */

#define PWM_INVERT_N_REPETITIONS 3U
#define INITIAL_PWM_FREQUENCY 24000U
#define INITIAL_PWM_DUTY 0.0f

#define PWM_MAX_IN_VOLTAGE 60.0f
#define PWM_MIN_IN_VOLTAGE 24.0f

#define PWM_MAX_OUT_VOLTAGE 10.0f

/**
 * ============================
 * Control
 * ============================
 */

#define CONTROL_INITIAL_GAIN_P 2.8f
#define CONTROL_INITIAL_GAIN_I 0.0f
#define CONTROL_INITIAL_GAIN_D 0.0f

#define CONTROL_SETPOINT_AVG_WINDOW 15U

#define CONTROL_ACTUATE_MAX_VALUE 1.0f
#define CONTROL_ACTUATE_MIN_VALUE -1.0f

#define CONTROL_ACTUATE_CUT_MIN_VALUE -0.1f
#define CONTROL_ACTUATE_CUT_MAX_VALUE 0.1f

#define CONTROL_INTEGRAL_MAX_VALUE 0.1f
#define CONTROL_INTEGRAL_MIN_VALUE -0.1f

/**
 * ============================
 * Beep
 * ============================
 */

#define STATUS_TONE_FREQUENCY_LOW_HZ 2093.0f
#define STATUS_TONE_FREQUENCY_MEDIUM_HZ 2794.0f
#define STATUS_TONE_FREQUENCY_HIGH_HZ 4186.0f
#define STATUS_TONE_DURATION_S 0.16f
#define STATUS_TONE_PWM_VOLUME 0.70f

#endif /** !__CONFIG_H__ */

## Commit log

2025-06-27 Create basic pin configuration using cubeMX
2025-06-27 Route power board layout
    [Switches.kicad_pcb, Switches.kicad_sch]
2025-06-27 Route control board layout
    [Powersupply.kicad_sch, can.kicad_sch, can_connector.kicad_sch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]
2025-07-14 Add UV fab files
    [can.kicad_sch, can_connector.kicad_sch, control.kicad_pcb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]
2025-07-27 Move hardware projects to subfolder
    [Powersupply.kicad_sch, Switches.kicad_pcb, Switches.kicad_sch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]
2025-07-27 Organize schematics per domain
    [Switches.kicad_pcb, Switches.kicad_sch, can.kicad_sch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]
2025-07-27 Add schematic hardware plots
    [control.kicad_sch]
2025-08-14 Modify max output voltage

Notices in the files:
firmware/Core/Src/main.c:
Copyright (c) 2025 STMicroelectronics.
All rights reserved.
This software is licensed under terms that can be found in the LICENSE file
